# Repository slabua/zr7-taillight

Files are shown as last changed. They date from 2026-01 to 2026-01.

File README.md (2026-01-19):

# ZR-7 ATtiny85 Tail Light







###### tags: `SLBLabs` `SLB Labs` `ZR-7` `ZR7` `ZR750` `Kawasaki` `KawasakiZR7` `TailLight` `TailLights` `ATtiny` `ATtiny85` `Arduino` `C/C++`

## A custom motorcycle tail light based on ATtiny85
> Hardware • Firmware • Animations • Automotive-grade considerations

Front

---

## ✦ Overview

The **ZR-7 Tail Light** is a custom-designed motorcycle tail light built around the **ATtiny85** microcontroller.  
It spans the complete stack, from schematic and PCB design to low-level firmware and animation logic, with a focus on robustness, simplicity, and visual clarity.

The goal of this project is not only to function as a tail light, but to serve as a well-engineered embedded system suitable for real automotive environments.

---

## ✦ Features

- ATtiny85-based control logic
- Addressable RGB LED layout
- Distinct operating modes:
  - Tail / running light
  - Brake light
  - Left / right indicators
- Deterministic, non-blocking firmware
- Designed for 12 V motorcycle electrical systems
- Compact, purpose-built PCB

---

## ✦ Hardware

Front-PCB3D

Front-PCB

### Core Components

- **MCU:** ATtiny85
- **LEDs:** Addressable RGB LEDs
- **Power:** 12 V input with on-board regulation
- **Inputs:** Brake, left indicator, right indicator

### Design Notes

Several constraints influenced the hardware design:

- **Automotive signal noise**
  Input conditioning and pull-down strategies are used to avoid floating or unstable states.

- **Power integrity**
  The circuit is designed to tolerate voltage fluctuations typical of motorcycle electrical systems.

- **Mechanical constraints**
  PCB shape, connector placement, and LED layout are optimized for the tail light enclosure.

Schematics, PCB layouts, and manufacturing files are included in the `hardware/` directory.

---

## ✦ Firmware

Firmware is written in **C**, targeting the ATtiny85 directly, with no operating system or dynamic memory usage.

### Architecture Highlights

- **State-based rendering**
  Tail, brake, and indicator logic are resolved into a single rendering pipeline.

- **Time-driven animations**
  All animations are non-blocking and tick-based.

- **Config-ready architecture**
  The firmware structure allows future addition of persistent configuration if needed.

Firmware source is located in the `firmware/` directory.

---

## ✦ Build & Flashing

The firmware is developed and flashed using the **Arduino IDE** with an external ISP programmer.

### Requirements

- Arduino IDE
- ATtiny board core (e.g. **ATTinyCore** by Spence Konde)
- Adafruit_NeoPixel library
- ISP programmer:
  - USBtinyISP
  - USBasp

### Arduino IDE Setup

1. Install the ATtiny board package via the Boards Manager.
2. Install the Adafruit_NeoPixel library via the Library Manager.
2. Connect the ISP programmer to the ATtiny85 ISP header.
3. In the Arduino IDE, configure:
   - **Board:** ATtiny85
   - **Clock:** 16.5 MHz
   - **B.O.D Level:** 4.3v
   - **Programmer:** USBtinyISP or USBasp

### Flashing

Use:

``Sketch → Upload Using Programmer``

This compiles the firmware and flashes it directly to the ATtiny85.  
No bootloader is used.

---

## ✦ Media

### PCB details


<details>
  <summary>[More]</summary>
  
  
  
  
  
</details>

---

### PCB assembly


<details>
  <summary>[More]</summary>
  
  
  
  
  
  
</details>

---

### Diffuser

  
<details>
  <summary>[More]</summary>

  
  
  
  
  
</details>

---

### Relay

  
<details>
  <summary>[More]</summary>

  
  
  
  
</details>

---

- [TODO] Installed tail light images
- [TODO] Short animation demo videos

※ Attached photographs of the assembled PCB are representative of Rev 1.0.

---

## ✦ Repository Layout

```
zr7-taillight/
├── firmware/        # ATtiny85 firmware source
├── hardware/        # Schematics and PCB design
├── docs/            # Images and additional documentation
└── README.md
```

---

## ✦ Safety & Disclaimer

⚠️ **Important Notice**

This project is provided **as-is**, for educational and experimental purposes.

- The author makes **no guarantees** regarding road legality, safety compliance, or fitness for any particular vehicle.
- Modifying vehicle lighting may be regulated or restricted depending on jurisdiction.
- You are solely responsible for ensuring that any implementation complies with **local laws**, **vehicle regulations**, and **safety requirements**.

Use at your own risk.

---

## ✦ Sponsorship

This project is sponsored by **PCBWay**.

PCBWay provided support for PCB manufacturing during the prototyping and validation stages of this project.

It was my first time trying their services and I am pleased with the results.  
The order flow was a little different than what I was used to, but I have been diligently followed thorough the whole process.  
Other than PCB manufacturing, PCBWay also offers services such as CNC and 3D printing. Be sure to check them out at https://www.pcbway.com/

---

## ✦ License

Released under the **MIT License**.
See the `LICENSE` file for details.

---

## ✦ Project Status

The project is **functional and actively evolving**.
Both hardware and firmware are stable, with ongoing refinements and documentation improvements planned.

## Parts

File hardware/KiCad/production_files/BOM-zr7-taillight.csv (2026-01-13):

Comment | Designator | Footprint | LCSC | Quantity
SMAJ5.0A | D3,D4,D5 | D_SMA | C113952 | 3
100n | C2,C3,C4,C5 | C_0603_1608Metric | C14663 | 4
SMBJ14A | D2 | D_SMB | C152106 | 1
10k | R1 | R_0805_2012Metric | C17414 | 1
1k | R4,R5,R6 | R_0805_2012Metric | C17513 | 3
22k | R10,R11,R12 | R_0805_2012Metric | C17560 | 3
330 | R16,R2,R3 | R_0805_2012Metric | C17630 | 3
4k7 | R7,R8,R9 | R_0805_2012Metric | C17673 | 3
1u | C6,C7,C8 | C_1206_3216Metric | C1848 | 3
D_Schottky | D1 | D_SMA | C22452 | 1
39k | R13,R14,R15 | R_0805_2012Metric | C25826 | 3
Polyfuse | F1 | SLB-Fuse_1812_4532Metric | C2843993 | 1
SW_DPDT_x2 | SW1 | SW_CK_JS202011CQN_DPDT_Straight | C431542 | 1
100u | C1 | CP_Elec_6.3x5.7 | C493460 | 1
Conn_01x04_Pin | J1 | SLB-Mini_DCDC | C5116483 | 1
WS2815 | U1,U10,U100,U11,U12,U13,U14,U15,U16,U17,U18,U19,U2,U20,U21,U22,U23,U24,U25,U26,U27,U28,U29,U3,U30,U31,U32,U33,U34,U35,U36,U37,U38,U39,U4,U40,U41,U42,U43,U44,U45,U46,U47,U48,U49,U5,U50,U51,U52,U53,U54,U55,U56,U57,U58,U59,U6,U60,U61,U62,U63,U64,U65,U66,U67,U68,U69,U7,U70,U71,U72,U73,U74,U75,U76,U77,U78,U79,U8,U80,U81,U82,U83,U84,U85,U86,U87,U88,U89,U9,U90,U91,U92,U93,U94,U95,U96,U97,U98,U99 | LED-TRICOLOR-5050 | C5446699 | 100
Conn_02x04_Counter_Clockwise | J2 | DIP-8_W7.62mm_Socket | C72129 | 1

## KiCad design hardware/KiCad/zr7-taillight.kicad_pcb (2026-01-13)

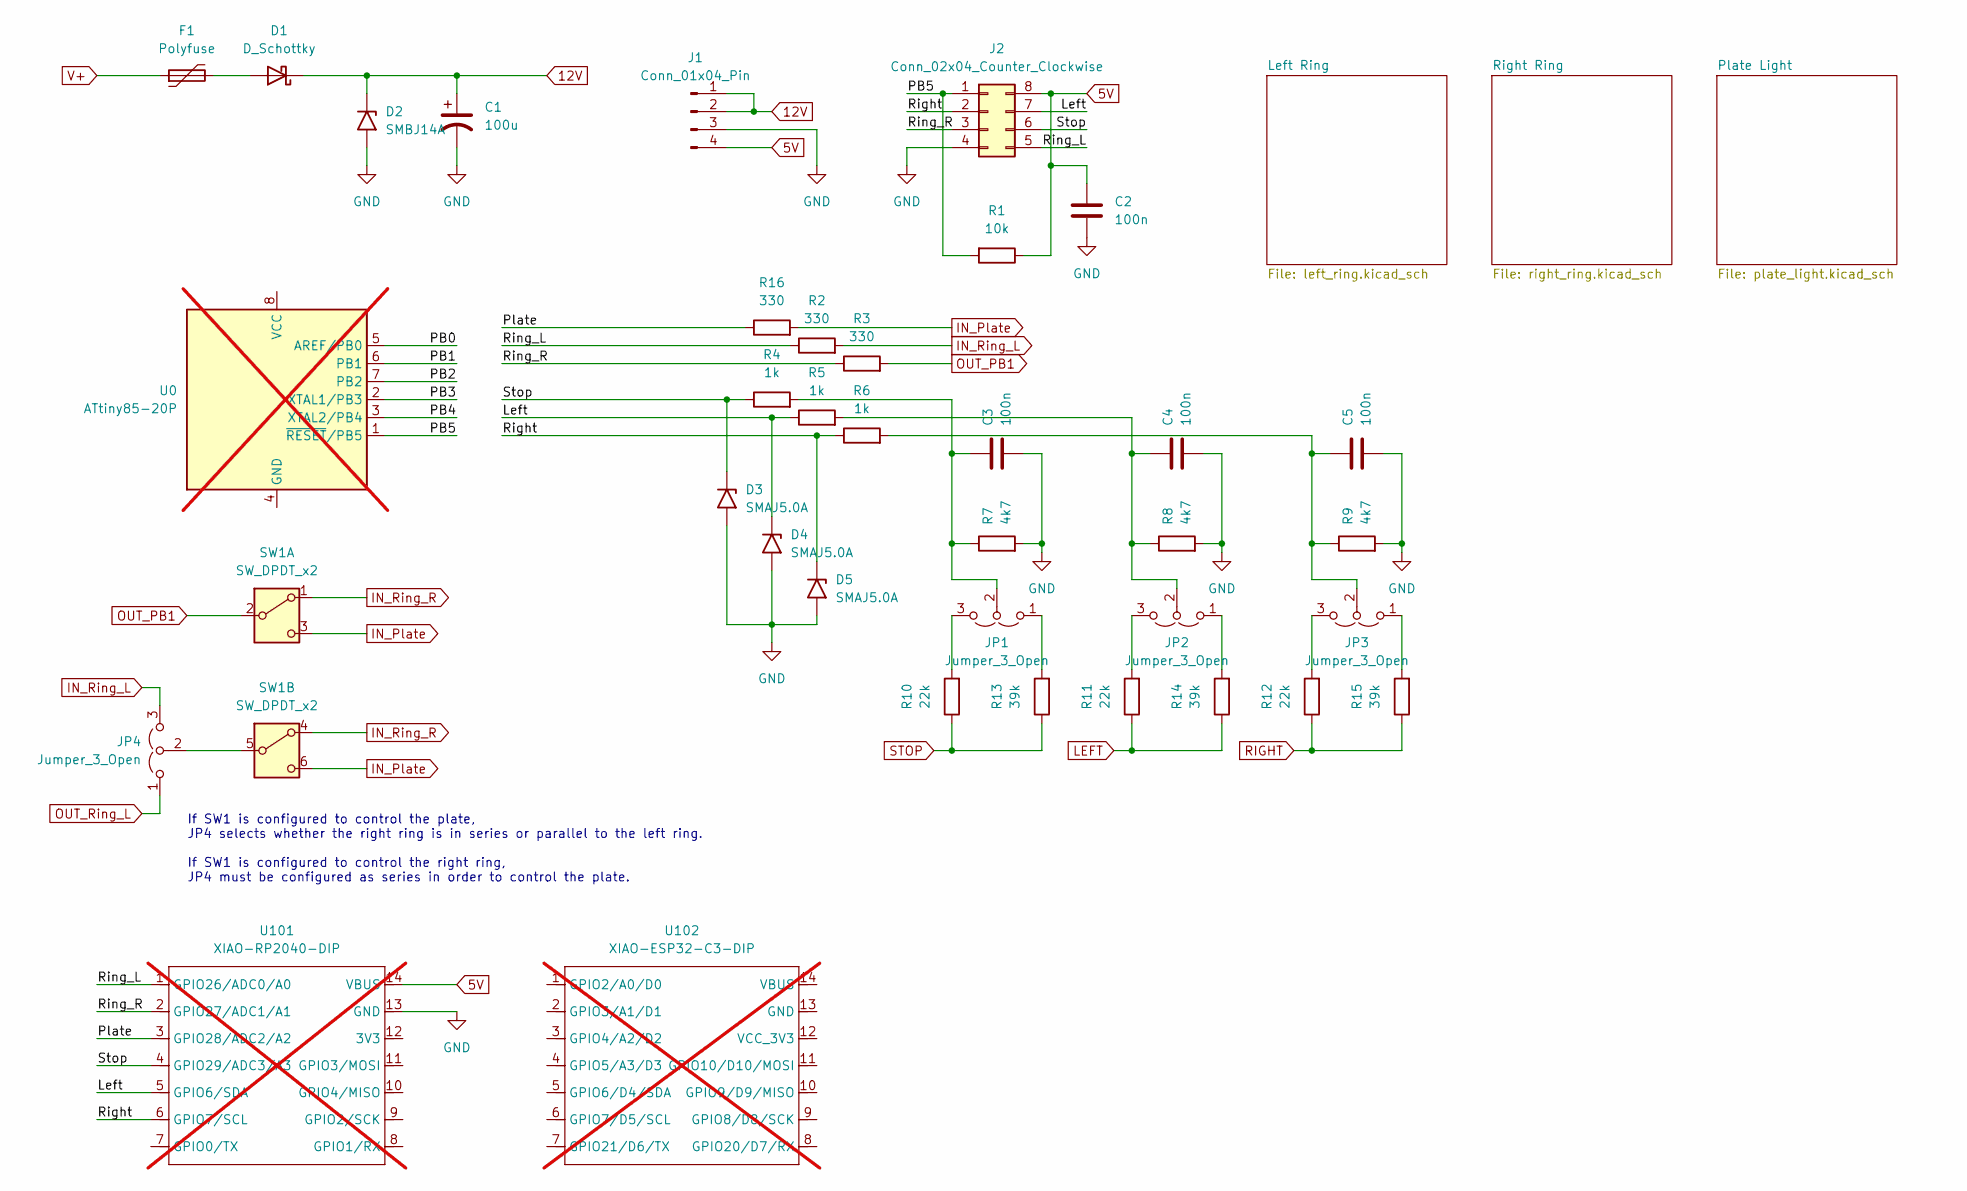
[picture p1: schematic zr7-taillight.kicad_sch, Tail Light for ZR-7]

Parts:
C1: 100u; CP_Elec_6.3x5.7; LCSC C493460
C2, C3, C4, C5: 100n; C_0603_1608Metric; LCSC C14663
D1: D_Schottky; D_SMA; LCSC C22452
D2: SMBJ14A; D_SMB; LCSC C152106
D3, D4, D5: SMAJ5.0A; D_SMA; LCSC C113952
F1: Polyfuse; SLB-Fuse_1812_4532Metric; LCSC C2843993
J1: Conn_01x04_Pin; SLB-Mini_DCDC; LCSC C5116483
J2: Conn_02x04_Counter_Clockwise; DIP-8_W7.62mm_Socket; LCSC C72129
JP1, JP2, JP3, JP4: Jumper_3_Open; PinHeader_1x03_P2.54mm_Vertical; LCSC C49257
R1: 10k; R_0805_2012Metric; LCSC C17414
R2, R3, R16: 330; R_0805_2012Metric; LCSC C17630
R4, R5, R6: 1k; R_0805_2012Metric; LCSC C17513
R7, R8, R9: 4k7; R_0805_2012Metric; LCSC C17673
R10, R11, R12: 22k; R_0805_2012Metric; LCSC C17560
R13, R14, R15: 39k; R_0805_2012Metric; LCSC C25826
SW1: SW_DPDT_x2; SW_CK_JS202011CQN_DPDT_Straight; LCSC C431542
U0: ATtiny85-20P; DIP-8_W7.62mm; not fitted
U101: XIAO-RP2040-DIP; not fitted
U102: XIAO-ESP32-C3-DIP; MOUDLE14P-XIAO-DIP-SMD; not fitted

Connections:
5V: C2.1, J1.4, J2.8, R1.1, U101.14 (VBUS)
12V: C1.1, D1.1 (K), D2.1 (A1), J1.1, J1.2; also elsewhere on the board
/Left: D4.1 (A1), J2.7, R5.1, U101.5 (GPIO6/SDA)
/PB5: J2.1, R1.2, U0.1 (~RESET/PB5)
/Plate: R16.1, U101.3 (GPIO28/ADC2/A2)
/Right: D5.1 (A1), J2.2, R6.1, U101.6 (GPIO7/SCL)
/Ring_L: J2.5, R2.1, U101.1 (GPIO26/ADC0/A0)
/Ring_R: J2.3, R3.1, U101.2 (GPIO27/ADC1/A1)
/Stop: D3.1 (A1), J2.6, R4.1, U101.4 (GPIO29/ADC3/A3)
GND: C1.2, C2.2, C3.2, C4.2, C5.2, D2.2 (A2), D3.2 (A2), D4.2 (A2), D5.2 (A2), J1.3, J2.4, R7.2, R8.2, R9.2, U101.13 (GND); also elsewhere on the board
IN_Plate: R16.2, SW1.3 (C), SW1.6 (C); also elsewhere on the board
IN_Ring_L: JP4.3 (B), R2.2; also elsewhere on the board
IN_Ring_R: SW1.1 (A), SW1.4 (A); also elsewhere on the board
LEFT: R11.1, R14.1
unnamed: D1.2 (A), F1.2
unnamed: JP1.1 (A), R13.2
unnamed: JP1.3 (B), R10.2
unnamed: C3.1, JP1.2 (C), R4.2, R7.1
unnamed: JP2.1 (A), R14.2
unnamed: JP2.3 (B), R11.2
unnamed: C4.1, JP2.2 (C), R5.2, R8.1
unnamed: JP3.1 (A), R15.2
unnamed: JP3.3 (B), R12.2
unnamed: C5.1, JP3.2 (C), R6.2, R9.1
unnamed: JP4.2 (C), SW1.5 (B)
OUT_PB1: R3.2, SW1.2 (B)
OUT_Ring_L: JP4.1 (A); also elsewhere on the board
RIGHT: R12.1, R15.1
STOP: R10.1, R13.1
V+: F1.1

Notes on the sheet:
If SW1 is configured to control the plate, JP4 selects whether the right ring is in series or parallel to the left ring. If SW1 is configured to control the right ring, JP4 must be configured as series in order to control the plate.

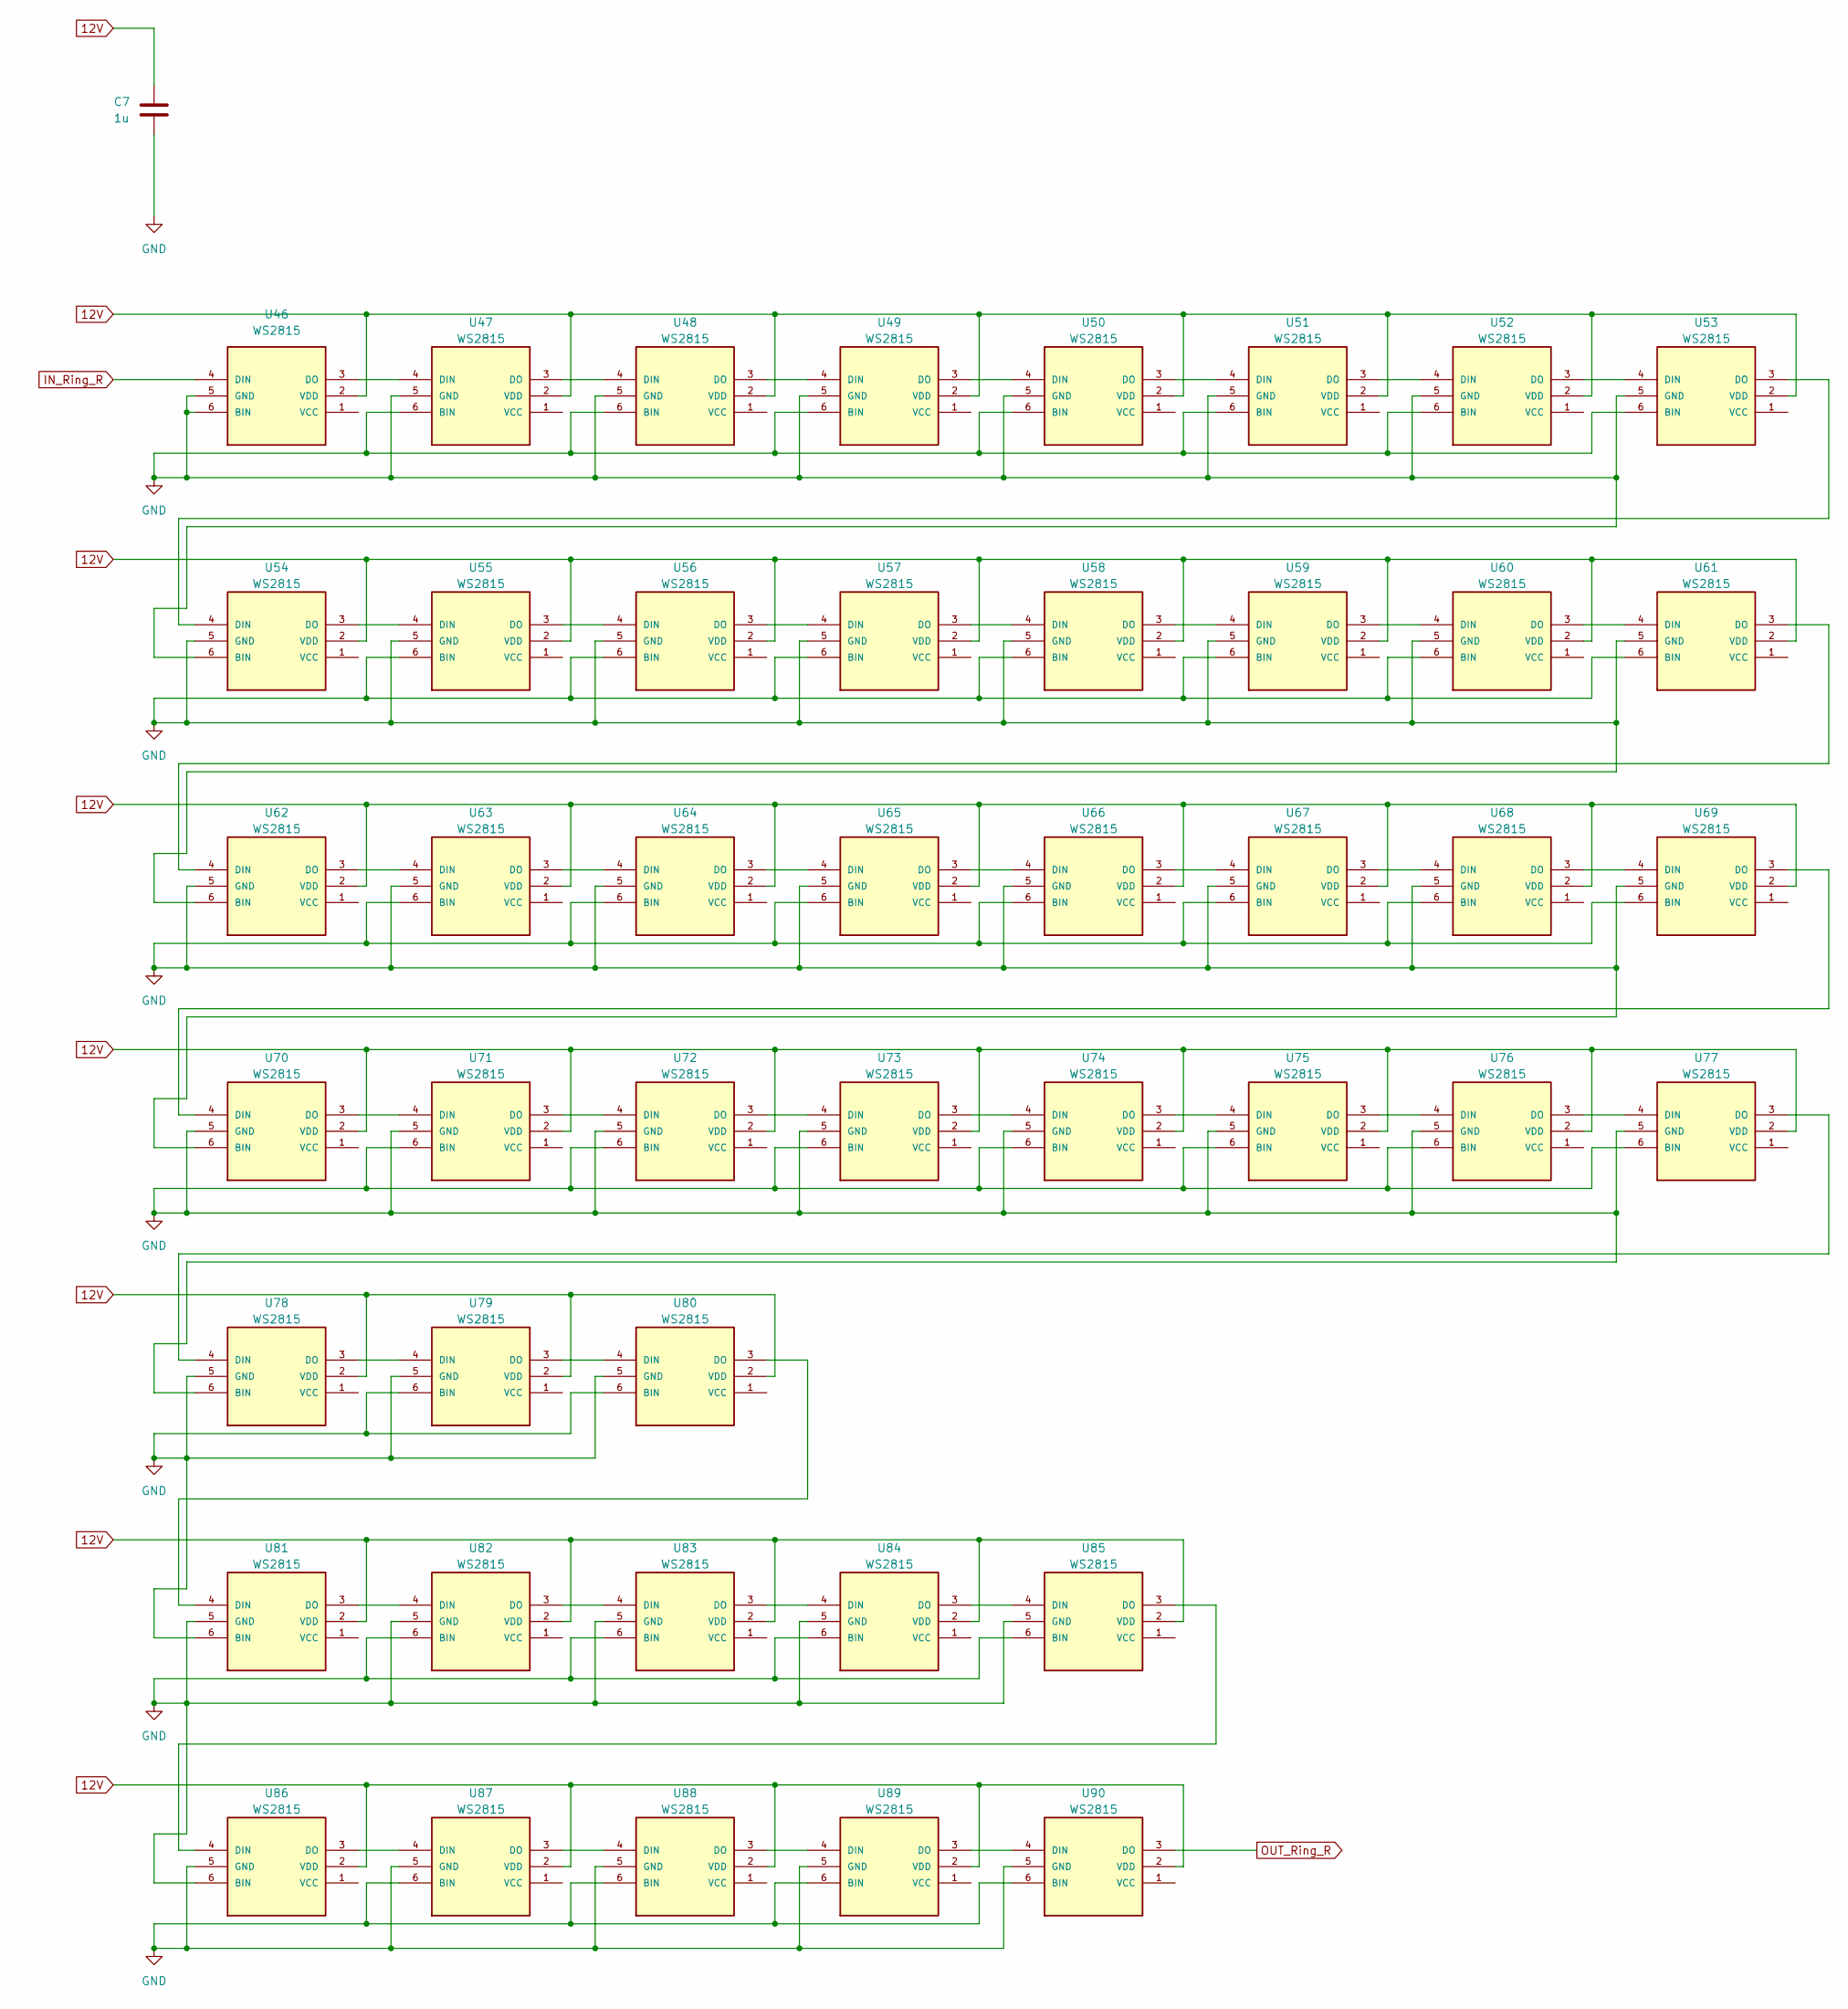
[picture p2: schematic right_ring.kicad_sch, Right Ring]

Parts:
C7: 1u; C_1206_3216Metric; LCSC C1848
U46, U47, U48, U49, U50, U51, U52, U53, U54, U55, U56, U57, U58, U59, U60, U61, U62, U63, U64, U65, U66, U67, U68, U69, U70, U71, U72, U73, U74, U75, U76, U77, U78, U79, U80, U81, U82, U83, U84, U85, U86, U87, U88, U89, U90: WS2815; LED-TRICOLOR-5050; LCSC C5446699

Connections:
12V: C7.1, U46.2 (VDD), U47.2 (VDD), U48.2 (VDD), U49.2 (VDD), U50.2 (VDD), U51.2 (VDD), U52.2 (VDD), U53.2 (VDD), U54.2 (VDD), U55.2 (VDD), U56.2 (VDD), U57.2 (VDD), U58.2 (VDD), U59.2 (VDD), U60.2 (VDD), U61.2 (VDD), U62.2 (VDD), U63.2 (VDD), U64.2 (VDD), U65.2 (VDD), U66.2 (VDD), U67.2 (VDD), U68.2 (VDD), U69.2 (VDD), U70.2 (VDD), U71.2 (VDD), U72.2 (VDD), U73.2 (VDD), U74.2 (VDD), U75.2 (VDD), U76.2 (VDD), U77.2 (VDD), U78.2 (VDD), U79.2 (VDD), U80.2 (VDD), U81.2 (VDD), U82.2 (VDD), U83.2 (VDD), U84.2 (VDD), U85.2 (VDD), U86.2 (VDD), U87.2 (VDD), U88.2 (VDD), U89.2 (VDD), U90.2 (VDD); also elsewhere on the board
GND: C7.2, U46.5 (GND), U46.6 (BIN), U47.5 (GND), U47.6 (BIN), U48.5 (GND), U48.6 (BIN), U49.5 (GND), U49.6 (BIN), U50.5 (GND), U50.6 (BIN), U51.5 (GND), U51.6 (BIN), U52.5 (GND), U52.6 (BIN), U53.5 (GND), U53.6 (BIN), U54.5 (GND), U54.6 (BIN), U55.5 (GND), U55.6 (BIN), U56.5 (GND), U56.6 (BIN), U57.5 (GND), U57.6 (BIN), U58.5 (GND), U58.6 (BIN), U59.5 (GND), U59.6 (BIN), U60.5 (GND), U60.6 (BIN), U61.5 (GND), U61.6 (BIN), U62.5 (GND), U62.6 (BIN), U63.5 (GND), U63.6 (BIN), U64.5 (GND), U64.6 (BIN), U65.5 (GND), U65.6 (BIN), U66.5 (GND), U66.6 (BIN), U67.5 (GND), U67.6 (BIN), U68.5 (GND), U68.6 (BIN), U69.5 (GND), U69.6 (BIN), U70.5 (GND), U70.6 (BIN), U71.5 (GND), U71.6 (BIN), U72.5 (GND), U72.6 (BIN), U73.5 (GND), U73.6 (BIN), U74.5 (GND), U74.6 (BIN), U75.5 (GND), U75.6 (BIN), U76.5 (GND), U76.6 (BIN), U77.5 (GND), U77.6 (BIN), U78.5 (GND), U78.6 (BIN), U79.5 (GND), U79.6 (BIN), U80.5 (GND), U80.6 (BIN), U81.5 (GND), U81.6 (BIN), U82.5 (GND), U82.6 (BIN), U83.5 (GND), U83.6 (BIN), U84.5 (GND), U84.6 (BIN), U85.5 (GND), U85.6 (BIN), U86.5 (GND), U86.6 (BIN), U87.5 (GND), U87.6 (BIN), U88.5 (GND), U88.6 (BIN), U89.5 (GND), U89.6 (BIN), U90.5 (GND), U90.6 (BIN); also elsewhere on the board
IN_Ring_R: U46.4 (DIN); also elsewhere on the board
unnamed: U46.3 (DO), U47.4 (DIN)
unnamed: U47.3 (DO), U48.4 (DIN)
unnamed: U48.3 (DO), U49.4 (DIN)
unnamed: U49.3 (DO), U50.4 (DIN)
unnamed: U50.3 (DO), U51.4 (DIN)
unnamed: U51.3 (DO), U52.4 (DIN)
unnamed: U52.3 (DO), U53.4 (DIN)
unnamed: U53.3 (DO), U54.4 (DIN)
unnamed: U54.3 (DO), U55.4 (DIN)
unnamed: U55.3 (DO), U56.4 (DIN)
unnamed: U56.3 (DO), U57.4 (DIN)
unnamed: U57.3 (DO), U58.4 (DIN)
unnamed: U58.3 (DO), U59.4 (DIN)
unnamed: U59.3 (DO), U60.4 (DIN)
unnamed: U60.3 (DO), U61.4 (DIN)
unnamed: U61.3 (DO), U62.4 (DIN)
unnamed: U62.3 (DO), U63.4 (DIN)
unnamed: U63.3 (DO), U64.4 (DIN)
unnamed: U64.3 (DO), U65.4 (DIN)
unnamed: U65.3 (DO), U66.4 (DIN)
unnamed: U66.3 (DO), U67.4 (DIN)
unnamed: U67.3 (DO), U68.4 (DIN)
unnamed: U68.3 (DO), U69.4 (DIN)
unnamed: U69.3 (DO), U70.4 (DIN)
unnamed: U70.3 (DO), U71.4 (DIN)
unnamed: U71.3 (DO), U72.4 (DIN)
unnamed: U72.3 (DO), U73.4 (DIN)
unnamed: U73.3 (DO), U74.4 (DIN)
unnamed: U74.3 (DO), U75.4 (DIN)
unnamed: U75.3 (DO), U76.4 (DIN)
unnamed: U76.3 (DO), U77.4 (DIN)
unnamed: U77.3 (DO), U78.4 (DIN)
unnamed: U78.3 (DO), U79.4 (DIN)
unnamed: U79.3 (DO), U80.4 (DIN)
unnamed: U80.3 (DO), U81.4 (DIN)
unnamed: U81.3 (DO), U82.4 (DIN)
unnamed: U82.3 (DO), U83.4 (DIN)
unnamed: U83.3 (DO), U84.4 (DIN)
unnamed: U84.3 (DO), U85.4 (DIN)
unnamed: U85.3 (DO), U86.4 (DIN)
unnamed: U86.3 (DO), U87.4 (DIN)
unnamed: U87.3 (DO), U88.4 (DIN)
unnamed: U88.3 (DO), U89.4 (DIN)
unnamed: U89.3 (DO), U90.4 (DIN)
OUT_Ring_R: U90.3 (DO)

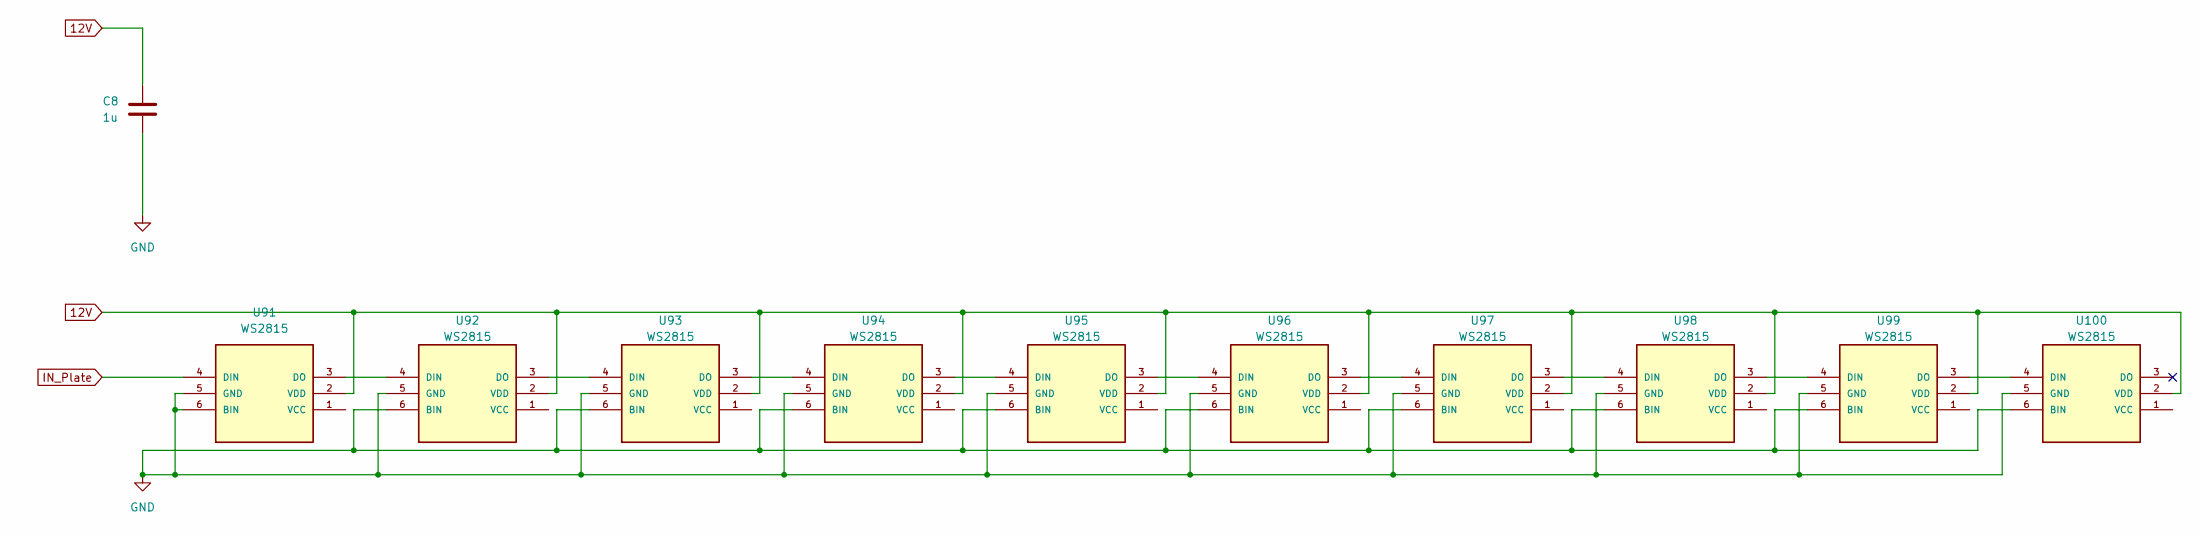
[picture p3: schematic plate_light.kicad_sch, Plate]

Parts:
C8: 1u; C_1206_3216Metric; LCSC C1848
U91, U92, U93, U94, U95, U96, U97, U98, U99, U100: WS2815; LED-TRICOLOR-5050; LCSC C5446699

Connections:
12V: C8.1, U91.2 (VDD), U92.2 (VDD), U93.2 (VDD), U94.2 (VDD), U95.2 (VDD), U96.2 (VDD), U97.2 (VDD), U98.2 (VDD), U99.2 (VDD), U100.2 (VDD); also elsewhere on the board
GND: C8.2, U91.5 (GND), U91.6 (BIN), U92.5 (GND), U92.6 (BIN), U93.5 (GND), U93.6 (BIN), U94.5 (GND), U94.6 (BIN), U95.5 (GND), U95.6 (BIN), U96.5 (GND), U96.6 (BIN), U97.5 (GND), U97.6 (BIN), U98.5 (GND), U98.6 (BIN), U99.5 (GND), U99.6 (BIN), U100.5 (GND), U100.6 (BIN); also elsewhere on the board
IN_Plate: U91.4 (DIN); also elsewhere on the board
unnamed: U91.3 (DO), U92.4 (DIN)
unnamed: U92.3 (DO), U93.4 (DIN)
unnamed: U93.3 (DO), U94.4 (DIN)
unnamed: U94.3 (DO), U95.4 (DIN)
unnamed: U95.3 (DO), U96.4 (DIN)
unnamed: U96.3 (DO), U97.4 (DIN)
unnamed: U97.3 (DO), U98.4 (DIN)
unnamed: U98.3 (DO), U99.4 (DIN)
unnamed: U99.3 (DO), U100.4 (DIN)

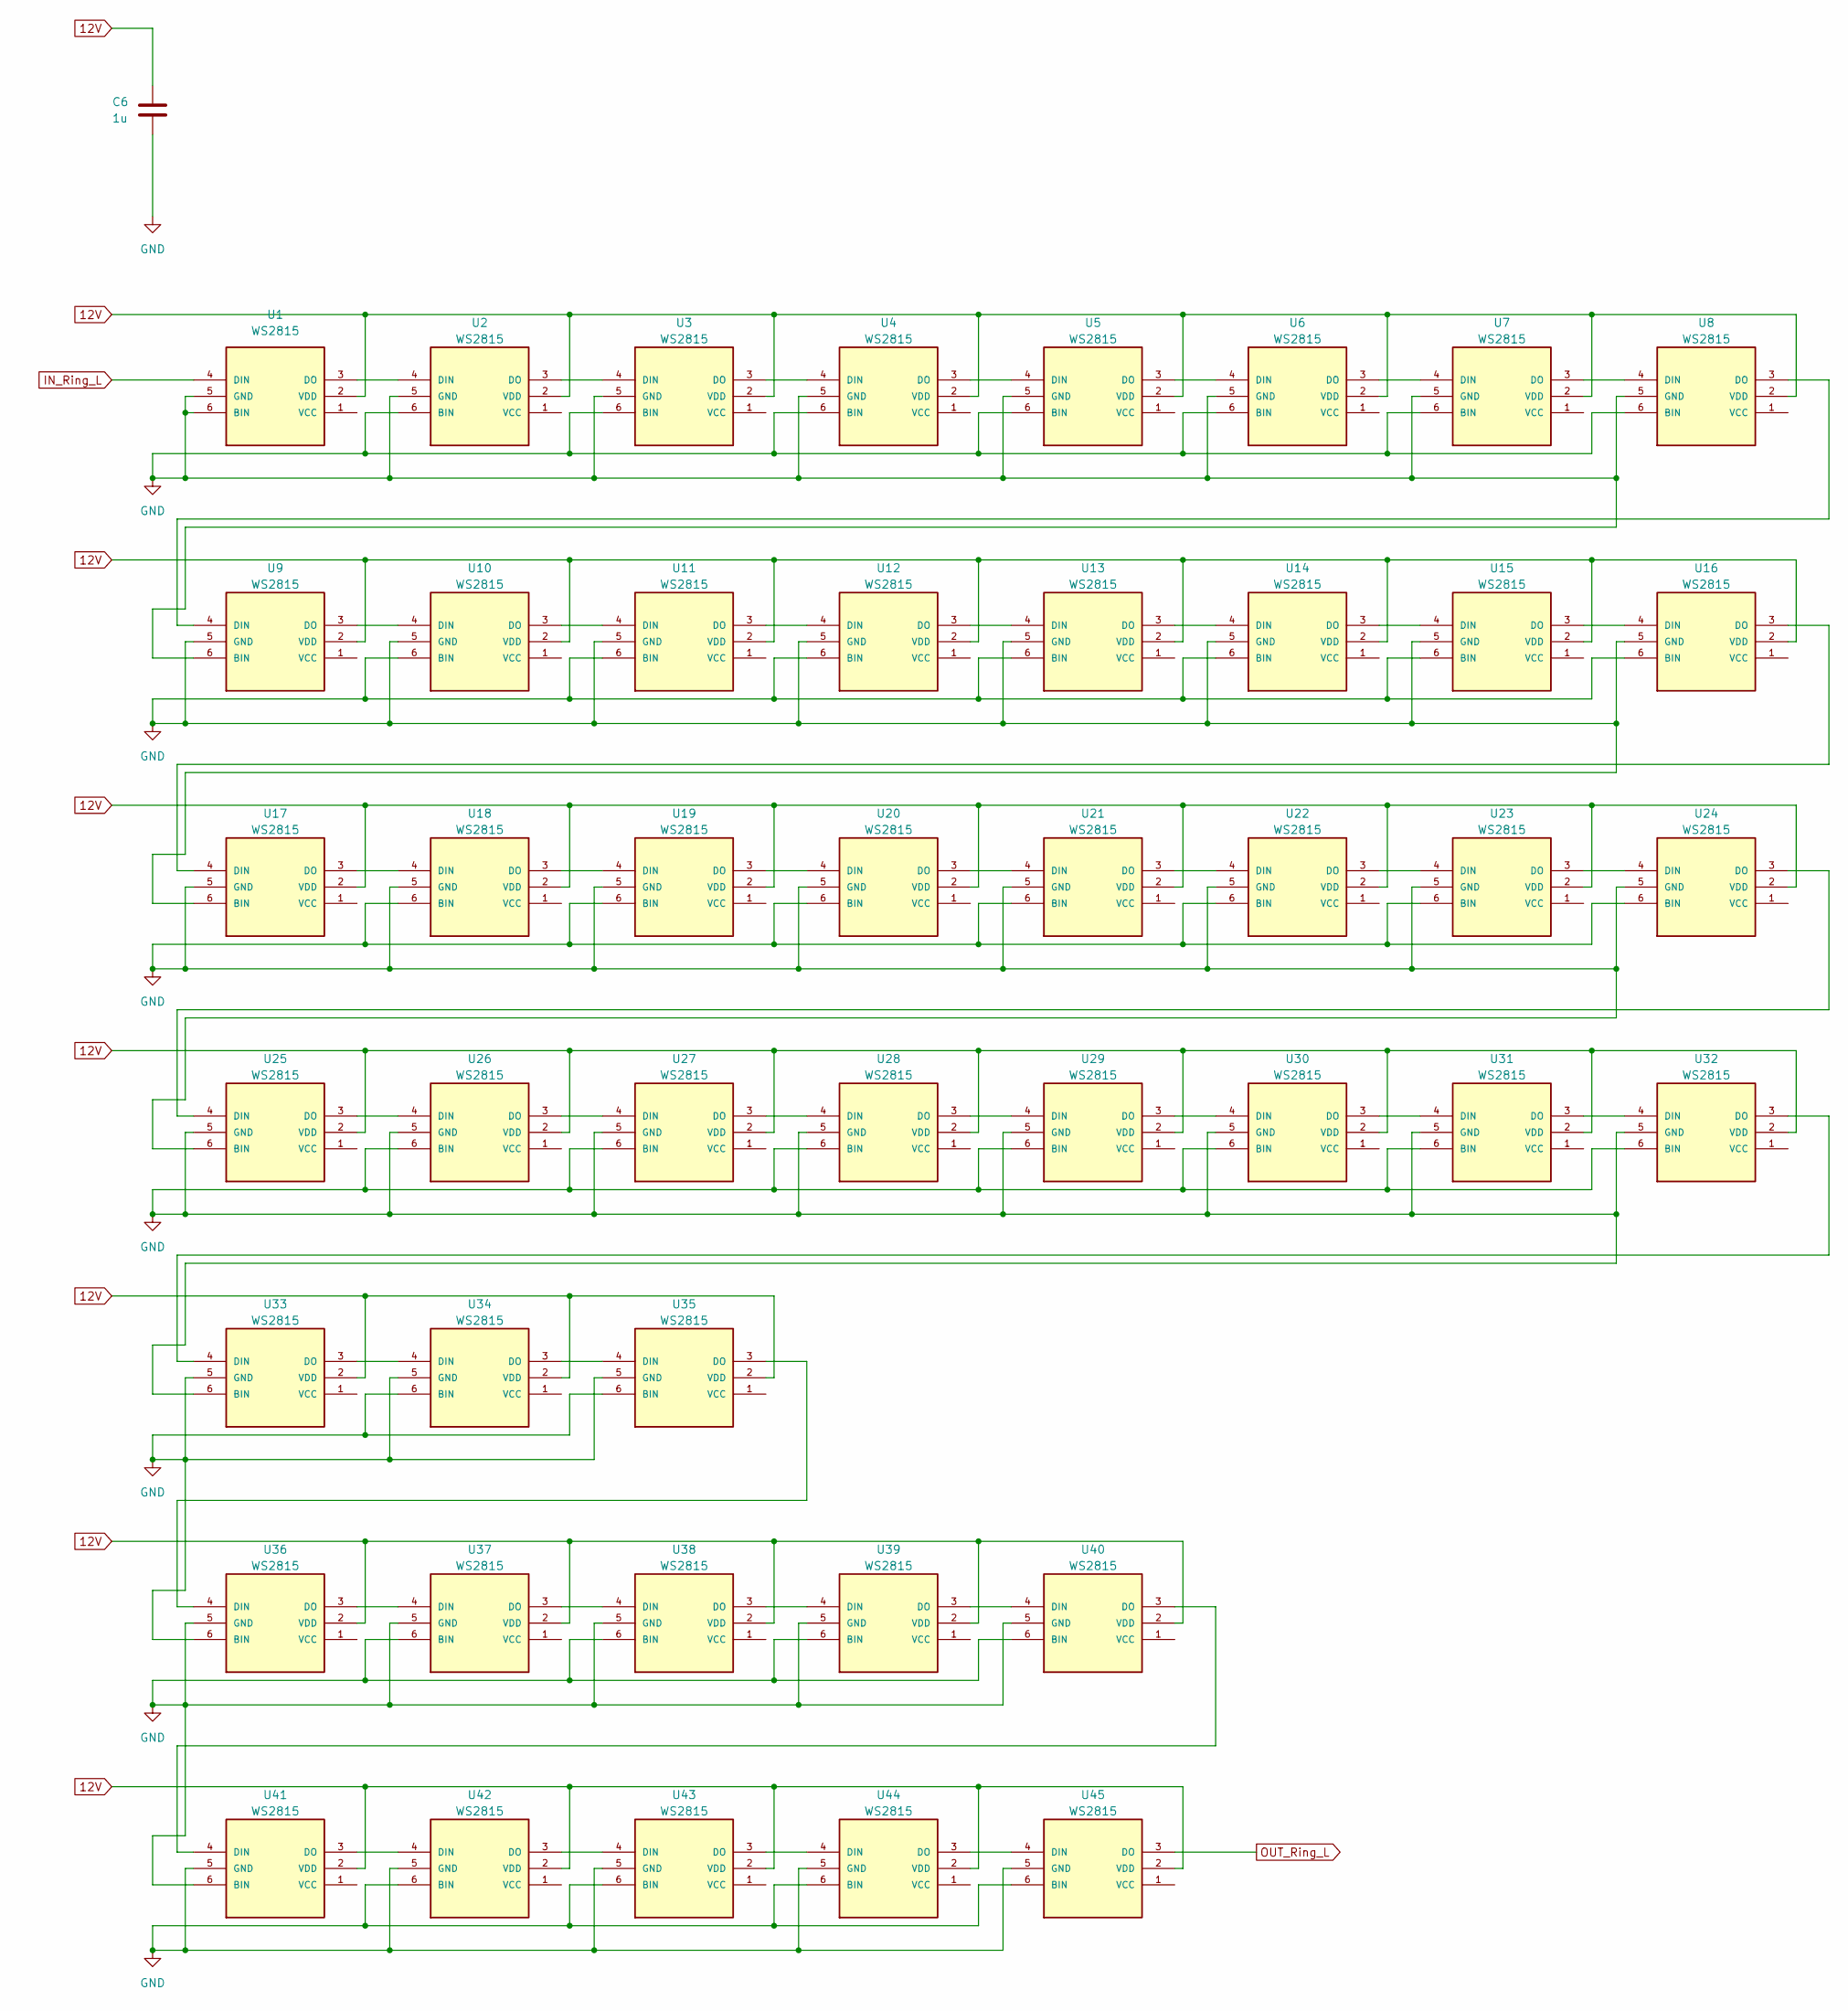
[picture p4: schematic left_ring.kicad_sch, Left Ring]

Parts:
C6: 1u; C_1206_3216Metric; LCSC C1848
U1, U2, U3, U4, U5, U6, U7, U8, U9, U10, U11, U12, U13, U14, U15, U16, U17, U18, U19, U20, U21, U22, U23, U24, U25, U26, U27, U28, U29, U30, U31, U32, U33, U34, U35, U36, U37, U38, U39, U40, U41, U42, U43, U44, U45: WS2815; LED-TRICOLOR-5050; LCSC C5446699

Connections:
12V: C6.1, U1.2 (VDD), U2.2 (VDD), U3.2 (VDD), U4.2 (VDD), U5.2 (VDD), U6.2 (VDD), U7.2 (VDD), U8.2 (VDD), U9.2 (VDD), U10.2 (VDD), U11.2 (VDD), U12.2 (VDD), U13.2 (VDD), U14.2 (VDD), U15.2 (VDD), U16.2 (VDD), U17.2 (VDD), U18.2 (VDD), U19.2 (VDD), U20.2 (VDD), U21.2 (VDD), U22.2 (VDD), U23.2 (VDD), U24.2 (VDD), U25.2 (VDD), U26.2 (VDD), U27.2 (VDD), U28.2 (VDD), U29.2 (VDD), U30.2 (VDD), U31.2 (VDD), U32.2 (VDD), U33.2 (VDD), U34.2 (VDD), U35.2 (VDD), U36.2 (VDD), U37.2 (VDD), U38.2 (VDD), U39.2 (VDD), U40.2 (VDD), U41.2 (VDD), U42.2 (VDD), U43.2 (VDD), U44.2 (VDD), U45.2 (VDD); also elsewhere on the board
GND: C6.2, U1.5 (GND), U1.6 (BIN), U2.5 (GND), U2.6 (BIN), U3.5 (GND), U3.6 (BIN), U4.5 (GND), U4.6 (BIN), U5.5 (GND), U5.6 (BIN), U6.5 (GND), U6.6 (BIN), U7.5 (GND), U7.6 (BIN), U8.5 (GND), U8.6 (BIN), U9.5 (GND), U9.6 (BIN), U10.5 (GND), U10.6 (BIN), U11.5 (GND), U11.6 (BIN), U12.5 (GND), U12.6 (BIN), U13.5 (GND), U13.6 (BIN), U14.5 (GND), U14.6 (BIN), U15.5 (GND), U15.6 (BIN), U16.5 (GND), U16.6 (BIN), U17.5 (GND), U17.6 (BIN), U18.5 (GND), U18.6 (BIN), U19.5 (GND), U19.6 (BIN), U20.5 (GND), U20.6 (BIN), U21.5 (GND), U21.6 (BIN), U22.5 (GND), U22.6 (BIN), U23.5 (GND), U23.6 (BIN), U24.5 (GND), U24.6 (BIN), U25.5 (GND), U25.6 (BIN), U26.5 (GND), U26.6 (BIN), U27.5 (GND), U27.6 (BIN), U28.5 (GND), U28.6 (BIN), U29.5 (GND), U29.6 (BIN), U30.5 (GND), U30.6 (BIN), U31.5 (GND), U31.6 (BIN), U32.5 (GND), U32.6 (BIN), U33.5 (GND), U33.6 (BIN), U34.5 (GND), U34.6 (BIN), U35.5 (GND), U35.6 (BIN), U36.5 (GND), U36.6 (BIN), U37.5 (GND), U37.6 (BIN), U38.5 (GND), U38.6 (BIN), U39.5 (GND), U39.6 (BIN), U40.5 (GND), U40.6 (BIN), U41.5 (GND), U41.6 (BIN), U42.5 (GND), U42.6 (BIN), U43.5 (GND), U43.6 (BIN), U44.5 (GND), U44.6 (BIN), U45.5 (GND), U45.6 (BIN); also elsewhere on the board
IN_Ring_L: U1.4 (DIN); also elsewhere on the board
unnamed: U1.3 (DO), U2.4 (DIN)
unnamed: U2.3 (DO), U3.4 (DIN)
unnamed: U3.3 (DO), U4.4 (DIN)
unnamed: U4.3 (DO), U5.4 (DIN)
unnamed: U5.3 (DO), U6.4 (DIN)
unnamed: U6.3 (DO), U7.4 (DIN)
unnamed: U7.3 (DO), U8.4 (DIN)
unnamed: U8.3 (DO), U9.4 (DIN)
unnamed: U9.3 (DO), U10.4 (DIN)
unnamed: U10.3 (DO), U11.4 (DIN)
unnamed: U11.3 (DO), U12.4 (DIN)
unnamed: U12.3 (DO), U13.4 (DIN)
unnamed: U13.3 (DO), U14.4 (DIN)
unnamed: U14.3 (DO), U15.4 (DIN)
unnamed: U15.3 (DO), U16.4 (DIN)
unnamed: U16.3 (DO), U17.4 (DIN)
unnamed: U17.3 (DO), U18.4 (DIN)
unnamed: U18.3 (DO), U19.4 (DIN)
unnamed: U19.3 (DO), U20.4 (DIN)
unnamed: U20.3 (DO), U21.4 (DIN)
unnamed: U21.3 (DO), U22.4 (DIN)
unnamed: U22.3 (DO), U23.4 (DIN)
unnamed: U23.3 (DO), U24.4 (DIN)
unnamed: U24.3 (DO), U25.4 (DIN)
unnamed: U25.3 (DO), U26.4 (DIN)
unnamed: U26.3 (DO), U27.4 (DIN)
unnamed: U27.3 (DO), U28.4 (DIN)
unnamed: U28.3 (DO), U29.4 (DIN)
unnamed: U29.3 (DO), U30.4 (DIN)
unnamed: U30.3 (DO), U31.4 (DIN)
unnamed: U31.3 (DO), U32.4 (DIN)
unnamed: U32.3 (DO), U33.4 (DIN)
unnamed: U33.3 (DO), U34.4 (DIN)
unnamed: U34.3 (DO), U35.4 (DIN)
unnamed: U35.3 (DO), U36.4 (DIN)
unnamed: U36.3 (DO), U37.4 (DIN)
unnamed: U37.3 (DO), U38.4 (DIN)
unnamed: U38.3 (DO), U39.4 (DIN)
unnamed: U39.3 (DO), U40.4 (DIN)
unnamed: U40.3 (DO), U41.4 (DIN)
unnamed: U41.3 (DO), U42.4 (DIN)
unnamed: U42.3 (DO), U43.4 (DIN)
unnamed: U43.3 (DO), U44.4 (DIN)
unnamed: U44.3 (DO), U45.4 (DIN)
OUT_Ring_L: U45.3 (DO); also elsewhere on the board

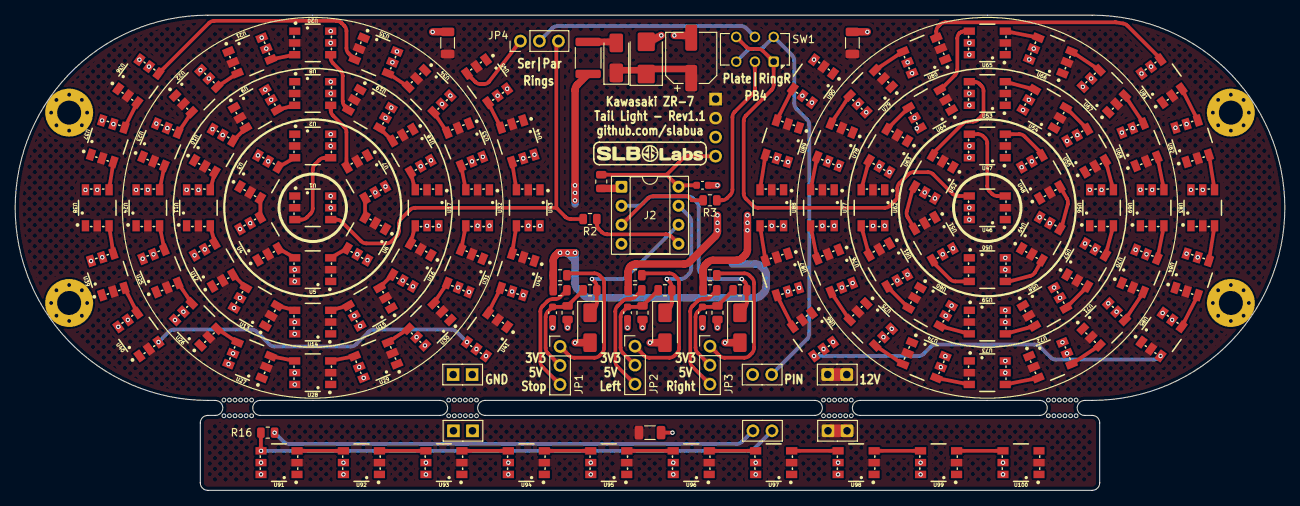
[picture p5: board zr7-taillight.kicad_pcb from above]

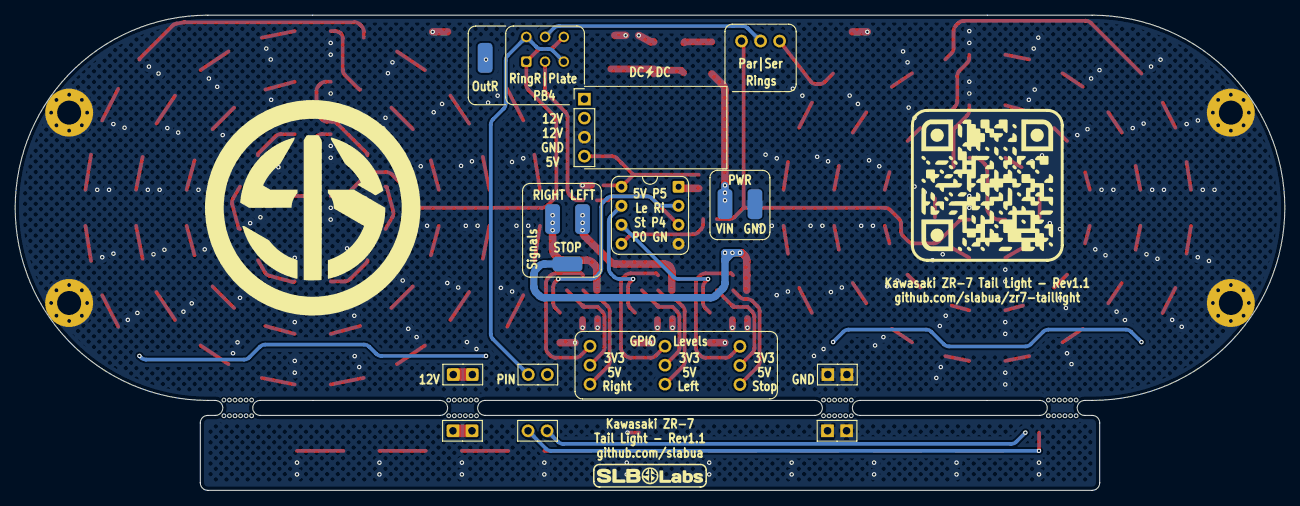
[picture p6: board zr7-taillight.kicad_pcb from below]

Board: 2 copper layers, 169.4 x 63.4 mm, 138 parts (2 on the bottom side), 125 nets.

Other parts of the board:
Ref**: SLBLabs LOGO only w-border

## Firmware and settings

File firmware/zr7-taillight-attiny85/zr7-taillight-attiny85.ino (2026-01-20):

// PB0: rings (Left + Right in parallel, mirrored, 45 LEDs total)
// PB4: numberplate (10 LEDs)
// Wiring Colour Codes
// Idle:  White (PWR)
// Stop:  Red
// Left:  Blue
// Right: Yellow
// GND:   Black (GND)

#include <Adafruit_NeoPixel.h>

// ---------------- CONFIG ----------------
#define RING_LEDS               45
#define PLATE_LEDS              10

#define RINGS_PIN               PB0
#define PLATE_PIN               PB4

#define PIN_STOP                PB1
#define PIN_LEFT                PB2
#define PIN_RIGHT               PB3

#define IDLE_MIN_BRIGHTNESS     5
#define IDLE_MAX_BRIGHTNESS     64
#define IDLE_SPAN               (IDLE_MAX_BRIGHTNESS - IDLE_MIN_BRIGHTNESS)
#define IDLE_PERIOD             2000  // breathing animation
#define IDLE_PERIOD_TICKS       (IDLE_PERIOD / 10)

#define STOP_BRIGHTNESS         200   // for R

#define PLATE_BRIGHTNESS        64    // for R, G, B
#define PLATE_TRAIL_LEN         2
//#define PLATE_STOP_TRAIL_LEN  2

#define BLINKER_TIMEOUT         2000
#define BLINKER_TIMEOUT_TICKS   (BLINKER_TIMEOUT / 10)
#define BLINKER_DEBOUNCE        20
#define BLINKER_DEBOUNCE_TICKS  ((BLINKER_DEBOUNCE + 49) / 50)  // 1

#define EMERG_LATCH_TICKS       50    // ~500 ms (confirmation)
#define EMERG_RELEASE_TICKS     150   // ~1.5 s (release)

#define LOOP_DELAY              10    // ms
#define RINGS_EMERG_DELAY       50    // ms
#define LOOP_DIVIDER            10
#define RINGS_EMERG_DIV         10
#define PLATE_STOP_DIV          10
#define RINGS_SWEEP_DIV         2
#define RINGS_SWEEP_TRAIL_LEN   3

#define BLINK_STEP_TICKS        2     // ticks per eyelid step
#define BLINK_INTERVAL_TICKS    500   // interval between blinks

// ---------------- MODE ----------------
enum Mode {
  MODE_IDLE,
  MODE_STOP,
  MODE_LEFT,
  MODE_RIGHT,
  MODE_EMERGENCY
};
static Mode currentMode = MODE_IDLE;

// -------------- EYEBLINK --------------
enum EyeBlinkState {
  BLINK_IDLE,
  BLINK_ACTIVE
};
static EyeBlinkState blinkState = BLINK_IDLE;

// blink sequence
static const int8_t blinkOrder[] = { +3, +2, +1, 0, -1, -2, -3 };
static const uint8_t BLINK_STEPS = sizeof(blinkOrder) / sizeof(blinkOrder[0]);

static bool blinkOpening = false;   // false = closing, true = opening
static int8_t blinkIndex = 0;
static uint8_t blinkTick = 0;

static const int8_t ledY[RING_LEDS] = {
  // ---- center ----
  /*  0 */  0,

  // ---- ring 1 (6) ----
  /*  1 */ +1,  // N
  /*  2 */ +1,
  /*  3 */ -1,
  /*  4 */ -1,  // S
  /*  5 */ -1,
  /*  6 */ +1,

  // ---- ring 2 (12) ----
  /*  7 */ +2,  /*  8 */ +2,      // N arc
  /*  9 */ +2,  /* 10 */  0,
  /* 11 */ -2,  /* 12 */ -2,
  /* 13 */ -2,  /* 14 */ -2,
  /* 15 */ -2,  /* 16 */  0,      // S arc
  /* 17 */ +2,  /* 18 */ +2,

  // ---- ring 3 (16) ----
  /* 19 */ +3,  /* 20 */ +3,  /* 21 */ +3,  // N arc
  /* 22 */ +2,  /* 23 */  0,
  /* 24 */ -2,  /* 25 */ -3,
  /* 26 */ -3,  /* 27 */ -3,
  /* 28 */ -3,  /* 29 */ -3,  /* 30 */ -2,  // S arc
  /* 31 */  0,  /* 32 */ +2,
  /* 33 */ +3,  /* 34 */ +3,

  // ---- left parenthesis (35–39) ----
  /* 35 */ +33,   // near 21
  /* 36 */ +33,
  /* 37 */  30,
  /* 38 */ -33,
  /* 39 */ -33,   // near 25

  // ---- right parenthesis (40–44) ----
  /* 40 */ -33,   // near 29
  /* 41 */ -33,
  /* 42 */  30,
  /* 43 */ +33,
  /* 44 */ +33    // near 33
};

// -------------- EMERGENCY RING BLINK --------------
enum RingEmergState {
  RING_EMERG_IDLE,
  RING_EMERG_ACTIVE
};
static RingEmergState ringEmergState = RING_EMERG_IDLE;

static const int8_t ringOrder[] = { 0, 1, 2, 3, 4 };
static const uint8_t RING_STEPS = sizeof(ringOrder) / sizeof(ringOrder[0]);

static int8_t ringEmergIndex = 0;
static bool ringOpening = false;
static uint8_t ringTick = 0;

static bool     emergencyLatched = false;
static uint16_t emergencyLatchTick = 0;
static uint16_t emergencyReleaseTick = 0;

static const int8_t ledRing[RING_LEDS] = {
  /*  0 */ 0,

  // ring 1
  /*  1 */ 1, /*  2 */ 1, /*  3 */ 1, /*  4 */ 1, /*  5 */ 1, /*  6 */ 1,

  // ring 2
  /*  7 */ 2, /*  8 */ 2, /*  9 */ 2, /* 10 */ 2,
  /* 11 */ 2, /* 12 */ 2, /* 13 */ 2, /* 14 */ 2,
  /* 15 */ 2, /* 16 */ 2,
  /* 17 */ 2, /* 18 */ 2,

  // ring 3
  /* 19 */ 3, /* 20 */ 3, /* 21 */ 3,
  /* 22 */ 3, /* 23 */ 3,
  /* 24 */ 3, /* 25 */ 3,
  /* 26 */ 3, /* 27 */ 3,
  /* 28 */ 3, /* 29 */ 3, /* 30 */ 3,
  /* 31 */ 3, /* 32 */ 3,
  /* 33 */ 3, /* 34 */ 3,

  // parentheses (outer accent ring)
  /* 35 */ 4, /* 36 */ 4, /* 37 */ 4, /* 38 */ 4, /* 39 */ 4,
  /* 40 */ 4, /* 41 */ 4, /* 42 */ 4, /* 43 */ 4, /* 44 */ 4
};


// ---------------- LED STRIPS ----------------
static Adafruit_NeoPixel rings(RING_LEDS, RINGS_PIN, NEO_GRB + NEO_KHZ800);
static Adafruit_NeoPixel plate(PLATE_LEDS, PLATE_PIN, NEO_GRB + NEO_KHZ800);

// timing
static uint16_t tick = 0;
static uint16_t animTick = 0;

// animation state
static bool ringsDirty = false;
static bool plateDirty = false;
static int8_t platePos = 0;
static int8_t  plateDir = 1;
//static int8_t plateDoubleIndex = 0;   // 0..4

// blinker pulse smoothing
static uint16_t lastLeftPulse  = 0;
static uint16_t lastRightPulse = 0;

// debounce
static bool lastLeftStateStable = LOW;
static bool lastRightStateStable = LOW;
static uint16_t lastLeftChangeTime = 0;
static uint16_t lastRightChangeTime = 0;

// ring direction (single ring only)
static const bool RING_CW = false;

struct PlateTrailProfile {
  int8_t  dir;
  bool    bounce;
  uint8_t r, g, b;
  uint8_t fill_r, fill_g, fill_b;
};

// ---------------- INDEX HELPER ----------------
static inline uint8_t ringIndex(uint8_t i, bool cw) {
  return cw ? i : (RING_LEDS - 1 - i);
}

// ---------------- COMMON HELPERS ----------------
/*
void fillRings(uint8_t r, uint8_t g, uint8_t b) {
  uint32_t colour = rings.Color(r, g, b);
  for (uint8_t i = 0; i < RING_LEDS; i++)
    rings.setPixelColor(i, colour);

  ringsDirty = true;
*/
void fillRings(uint8_t r, uint8_t g, uint8_t b, uint8_t start = 0, uint8_t end = RING_LEDS - 1) {
  if (start >= RING_LEDS) return;
  if (end   >= RING_LEDS) end = RING_LEDS - 1;
  if (start > end) return;

  uint32_t colour = rings.Color(r, g, b);

  for (uint8_t i = start; i <= end; i++) {
    rings.setPixelColor(i, colour);
  }

  ringsDirty = true;
}


void fillPlate(uint8_t r, uint8_t g, uint8_t b) {
  uint32_t colour = plate.Color(r, g, b);
  
  for (uint8_t i = 0; i < PLATE_LEDS; i++) {
    plate.setPixelColor(i, colour);
  }

  plateDirty = true;
}

static inline void fadePlateTo(uint8_t bg_r, uint8_t bg_g, uint8_t bg_b, uint8_t decay) {
  for (uint8_t i = 0; i < PLATE_LEDS; i++) {
    uint32_t c = plate.getPixelColor(i);

    uint8_t r = (uint8_t)(c >> 16);
    uint8_t g = (uint8_t)(c >> 8);
    uint8_t b = (uint8_t)c;

    // move each channel toward background by 'decay' steps
    if (r > bg_r) r = (r - decay > bg_r) ? r - decay : bg_r;
    else if (r < bg_r) r = (r + decay < bg_r) ? r + decay : bg_r;

    if (g > bg_g) g = (g - decay > bg_g) ? g - decay : bg_g;
    else if (g < bg_g) g = (g + decay < bg_g) ? g + decay : bg_g;

    if (b > bg_b) b = (b - decay > bg_b) ? b - decay : bg_b;
    else if (b < bg_b) b = (b + decay < bg_b) ? b + decay : bg_b;

    plate.setPixelColor(i, plate.Color(r, g, b));
  }

  plateDirty = true;
}

static inline void fadePlate(uint8_t decay) { // to black
  fadePlateTo(0, 0, 0, decay);
}

static inline void advancePlatePos(bool bounce) {
  platePos += plateDir;

  if (bounce) {
    if (platePos <= 0) {
      platePos = 0;
      plateDir = +1;
    } else if (platePos >= PLATE_LEDS - 1) {
      platePos = PLATE_LEDS - 1;
      plateDir = -1;
    }
  } else {
    if (platePos < 0)
      platePos = PLATE_LEDS - 1;
    else if (platePos >= PLATE_LEDS)
      platePos = 0;
  }
}

static inline void renderPlateTrailEx(const PlateTrailProfile& profile) {
  if ((animTick % PLATE_STOP_DIV) != 0) return;

  if (!profile.bounce)
    plateDir = (profile.dir == 0) ? +1 : profile.dir;

  fillPlate(profile.fill_r, profile.fill_g, profile.fill_b);

  advancePlatePos(profile.bounce);

  // -------- NORMAL SWEEP (dir != 0) --------
  if (profile.dir != 0) {
    for (uint8_t i = 0; i < PLATE_TRAIL_LEN; i++) {
      int16_t p = platePos - (plateDir * i);
      if (p < 0 || p >= PLATE_LEDS) break;

      uint8_t v = 255 - (i * (255 / PLATE_TRAIL_LEN));
      plate.setPixelColor(
        p,
        plate.Color(
          (uint16_t)profile.r * v / 255,
          (uint16_t)profile.g * v / 255,
          (uint16_t)profile.b * v / 255
        )
      );
    }
  }

  // -------- DOUBLE SWEEP (dir == 0) --------
  else {
    const uint8_t half = PLATE_LEDS / 2;

    // abstract position inside half-domain
    uint8_t pos = platePos % half;

    for (uint8_t i = 0; i < PLATE_TRAIL_LEN; i++) {
      int16_t p = pos - i;
      if (p < 0) break;

      uint8_t v = 255 - (i * (255 / PLATE_TRAIL_LEN));

      uint8_t left  = (half - 1) - p;
      uint8_t right = half + p;

      if (left < PLATE_LEDS)
        plate.setPixelColor(
          left,
          plate.Color(
            (uint16_t)profile.r * v / 255,
            (uint16_t)profile.g * v / 255,
            (uint16_t)profile.b * v / 255
          )
        );

      if (right < PLATE_LEDS)
        plate.setPixelColor(
          right,
          plate.Color(
            (uint16_t)profile.r * v / 255,
            (uint16_t)profile.g * v / 255,
            (uint16_t)profile.b * v / 255
          )
        );
    }
  }

  plateDirty = true;
}

static inline void renderSweepTrailEx(uint8_t start, uint8_t count, const PlateTrailProfile& profile) {
  if ((animTick % RINGS_SWEEP_DIV) != 0) return;

  static int16_t sweepPos = 0;
  static int8_t  sweepDir = +1;

  /* direction is explicitly +1 or -1 */
  sweepDir = (profile.dir >= 0) ? +1 : -1;

  /* fill ring subsection using existing helper */
//  fillRings(
//    profile.fill_r,
//    profile.fill_g,
//    profile.fill_b,
//    start,
//    start + count - 1
//  );

  /* advance position (wrap only) */
  sweepPos += sweepDir;
  if (sweepPos >= count) sweepPos = 0;
  if (sweepPos < 0)      sweepPos = count - 1;

  /* normal sweep with trail */
  for (uint8_t i = 0; i < RINGS_SWEEP_TRAIL_LEN; i++) {
    int16_t p = sweepPos - (sweepDir * i);
    if (p < 0 || p >= count) break;

    uint8_t v = 255 - (i * (255 / RINGS_SWEEP_TRAIL_LEN));

    rings.setPixelColor(
      start + p,
      rings.Color(
        (uint16_t)profile.r * v / 255,
        (uint16_t)profile.g * v / 255,
        (uint16_t)profile.b * v / 255
      )
    );
  }

  ringsDirty = true;
}


//static void renderEyeBlink(int8_t activeLevel, bool turnOn) {
//  uint32_t colour = rings.Color(55, 0, 0);
//
//  for (uint8_t i = 0; i < RING_LEDS; i++) {
//    if (ledY[i] == activeLevel) {
//      rings.setPixelColor(i, turnOn ? colour : 0);
//    }
//  }
//
//  ringsDirty = true;
//}

static inline void updateEmergencyState(bool leftActive, bool rightActive) {
  if (leftActive && rightActive) {
    emergencyLatched = true;
    emergencyLatchTick = tick;
    emergencyReleaseTick = 0;
  } else if (emergencyLatched) {
    // count how long both are inactive
    if (!leftActive && !rightActive) {
      if (emergencyReleaseTick == 0)
        emergencyReleaseTick = tick;
      else if ((uint16_t)(tick - emergencyReleaseTick) >= EMERG_RELEASE_TICKS)
        emergencyLatched = false;
    } else {
      emergencyReleaseTick = 0;
    }
  }
}

// ---------------- RING ANIMATIONS ----------------
void animRingsIdle(uint16_t animTick) {
  uint16_t idle_t = animTick % IDLE_PERIOD_TICKS;

  uint8_t idle_wave =
    (idle_t < IDLE_PERIOD_TICKS / 2)
      ? (uint32_t)idle_t * (IDLE_SPAN * 2) / IDLE_PERIOD_TICKS
      : (uint32_t)(IDLE_PERIOD_TICKS - idle_t) * (IDLE_SPAN * 2) / IDLE_PERIOD_TICKS;

  uint8_t idle_val = IDLE_MIN_BRIGHTNESS + idle_wave;
  uint32_t colour = rings.Color(idle_val, (idle_val / 10) + 1, 0);

  for (uint8_t i = 0; i < RING_LEDS; i++)
    rings.setPixelColor(ringIndex(i, RING_CW), colour);
    //rings.setPixelColor(i, colour);
//  for (uint8_t i = 0; i < 19; i++)
//    rings.setPixelColor(ringIndex(i, RING_CW), colour);
//    //rings.setPixelColor(i, colour);

  fillRings(0, 0, IDLE_MAX_BRIGHTNESS, 35, 44);

  ringsDirty = true;
}

void animRingsStop() {
  /*
  uint32_t colour = rings.Color(STOP_BRIGHTNESS, 10, 0);
  for (uint8_t i = 0; i < RING_LEDS; i++)
    rings.setPixelColor(i, colour);
  */
  
  fillRings(STOP_BRIGHTNESS, 5, 0, 0, 34);
  fillRings(255, 5, 0, 35, 44);
  
  ringsDirty = true;
}

void animRingsTurn(uint16_t animTick) {
  rings.clear();

  uint8_t pos = animTick % RING_LEDS;

  rings.setPixelColor(ringIndex(pos, RING_CW), rings.Color(255, 80, 0));

  ringsDirty = true;
}

void animRingsEmergency(uint16_t animTick) {
  uint8_t phase = (animTick / RINGS_EMERG_DELAY) & 1;
  uint8_t val = phase ? 0 : 55;

  uint32_t colour = rings.Color(val, val / 4, 0);

  for (uint8_t i = 0; i < RING_LEDS; i++)
    rings.setPixelColor(i, colour);

  ringsDirty = true;
}

void animRingsEmergencyRings() {
  if (ringEmergState != RING_EMERG_ACTIVE)
    return;

  // ---- timing gate ----
  if (++ringTick < RINGS_EMERG_DIV)
    return;
  ringTick = 0;

  uint32_t colour = rings.Color(255, 80, 0);
  int8_t level = ringOrder[ringEmergIndex];

  for (uint8_t i = 0; i < RING_LEDS; i++) {
    if (ledRing[i] == level) {
      rings.setPixelColor(i, ringOpening ? colour : 0);
    }
  }

  ringsDirty = true;

  // ---- advance ----
  if (!ringOpening) {
    ringEmergIndex++;
    if (ringEmergIndex >= RING_STEPS) {
      ringEmergIndex = RING_STEPS - 1;
      ringOpening = true;
    }
  } else {
    ringEmergIndex--;
    if (ringEmergIndex < 0) {
      ringEmergIndex = 0;
      ringOpening = false;
    }
  }
}

void startEmergencyRingAnim() {
  ringEmergIndex = 0;
  ringOpening = false;
  ringTick = 0;
  ringEmergState = RING_EMERG_ACTIVE;
}

void stopEmergencyRingAnim() {
  ringEmergState = RING_EMERG_IDLE;
}

void animRingsEyeBlink() {
  if (blinkState != BLINK_ACTIVE)
    return;

  // ---- timing gate ----
  if (++blinkTick < BLINK_STEP_TICKS)
    return;
  blinkTick = 0;

  uint32_t colour = rings.Color(
        (currentMode == MODE_STOP) ? STOP_BRIGHTNESS : IDLE_MAX_BRIGHTNESS, 10, 0);

  int8_t level = blinkOrder[blinkIndex];

  for (uint8_t i = 0; i < RING_LEDS; i++) {
    if (ledY[i] == level) {
      rings.setPixelColor(i, blinkOpening ? colour : 0);
    }
  }

  ringsDirty = true;

  // ---- advance ----
  if (!blinkOpening) {
    if (blinkIndex < BLINK_STEPS - 1) {
      blinkIndex++;
    } else {
      // we have already rendered the last step
      blinkOpening = true;
    }
  } else {
    blinkIndex--;
    if (blinkIndex < 0) {
      blinkState = BLINK_IDLE;
    }
  }
}

void startEyeBlink() {
  /*
  uint32_t colour = rings.Color(STOP_BRIGHTNESS, 0, 0);

  // ensure fully open
  for (uint8_t i = 0; i < RING_LEDS; i++) {
    rings.setPixelColor(i, colour);
  }

  ringsDirty = true;
  */

  blinkIndex = 0;
  blinkOpening = false;
  blinkTick = 0;
  blinkState = BLINK_ACTIVE;
}

// ---------------- NUMBERPLATE ----------------
void animPlateIdle() {
  fillPlate(PLATE_BRIGHTNESS, PLATE_BRIGHTNESS, PLATE_BRIGHTNESS - 5);
}

static const PlateTrailProfile PLATE_IDLE  = { +1, true,  255, 10, 0, PLATE_BRIGHTNESS, PLATE_BRIGHTNESS, PLATE_BRIGHTNESS - 5 };
static const PlateTrailProfile PLATE_STOP  = { +1, true,  255, 80, 0, 0, 0, 0 };
static const PlateTrailProfile PLATE_LEFT  = { -1, false, 255, 80, 0, 0, 0, 0 };
static const PlateTrailProfile PLATE_RIGHT = { +1, false, 255, 80, 0, 0, 0, 0 };
static const PlateTrailProfile PLATE_EMERG = { +1, true,  255, 80, 0, 0, 0, 0 };
static const PlateTrailProfile PLATE_EMERG_DOUBLE = { 0, false, 255, 80, 0, 0, 0, 0 };

void animPlateIdleTrail()  { renderPlateTrailEx(PLATE_IDLE); }
void animPlateStopTrail()  { renderPlateTrailEx(PLATE_STOP); }
void animPlateLeftTrail()  { renderPlateTrailEx(PLATE_LEFT); }
void animPlateRightTrail() { renderPlateTrailEx(PLATE_RIGHT); }
void animPlateEmergTrail() { renderPlateTrailEx(PLATE_EMERG); }
void animPlateEmergDoubleTrail() { renderPlateTrailEx(PLATE_EMERG_DOUBLE); }

void animRingOverlayTrail() { renderSweepTrailEx(19, 16, PLATE_RIGHT); }

/*
void animPlateDoubleSweepTrail() {
  if ((animTick % PLATE_STOP_DIV) != 0)
    return;

  // background
  fillPlate(
    PLATE_EMERG_DOUBLE.fill_r,
    PLATE_EMERG_DOUBLE.fill_g,
    PLATE_EMERG_DOUBLE.fill_b
  );

  // ---- primary heads ----
  int8_t left  = 4 - plateDoubleIndex;
  int8_t right = 5 + plateDoubleIndex;

  uint32_t headColor = plate.Color(
    PLATE_EMERG_DOUBLE.r,
    PLATE_EMERG_DOUBLE.g,
    PLATE_EMERG_DOUBLE.b
  );

  if (left >= 0)
    plate.setPixelColor(left, headColor);

  if (right < PLATE_LEDS)
    plate.setPixelColor(right, headColor);

  // ---- trail ----
  for (uint8_t i = 1; i < PLATE_TRAIL_LEN; i++) {
    uint8_t v = 255 - (i * (255 / PLATE_TRAIL_LEN));

    uint32_t trailColor = plate.Color(
      (uint16_t)PLATE_EMERG_DOUBLE.r * v / 255,
      (uint16_t)PLATE_EMERG_DOUBLE.g * v / 255,
      (uint16_t)PLATE_EMERG_DOUBLE.b * v / 255
    );

    int8_t l = left  + i;
    int8_t r = right - i;

    if (l >= 0 && l < PLATE_LEDS)
      plate.setPixelColor(l, trailColor);

    if (r >= 0 && r < PLATE_LEDS)
      plate.setPixelColor(r, trailColor);
  }

  plateDirty = true;

  // ---- advance ----
  plateDoubleIndex++;
  if (plateDoubleIndex > 4)
    plateDoubleIndex = 0;
}
*/

/*
void animPlateStop() {
  static uint8_t div = 0;
  if (++div < PLATE_STOP_DIV) return;
  div = 0;

  fillPlate(PLATE_BRIGHTNESS, PLATE_BRIGHTNESS, PLATE_BRIGHTNESS);
  plate.setPixelColor(platePos, plate.Color(255, 0, 0));

  //plate.show();
  plateDirty = true;

  platePos += plateDir;
  if (platePos == 0 || platePos == PLATE_LEDS - 1)
    plateDir = -plateDir;
}

void animPlateLeft() {
  fillPlate(PLATE_BRIGHTNESS, PLATE_BRIGHTNESS, PLATE_BRIGHTNESS);
  plate.setPixelColor(platePos, plate.Color(255, 80, 0));

  //plate.show();
  plateDirty = true;

  platePos++;
  if (platePos >= PLATE_LEDS)
    platePos = 0;
}

void animPlateRight() {
  fillPlate(PLATE_BRIGHTNESS, PLATE_BRIGHTNESS, PLATE_BRIGHTNESS);
  plate.setPixelColor(platePos, plate.Color(255, 80, 0));

  //plate.show();
  plateDirty = true;

  if (platePos == 0)
    platePos = PLATE_LEDS - 1;
  else
    platePos--;
}
*/

// ---------------- MODE MGMT ----------------
void setMode(Mode m) {
  if (m != currentMode) {
    currentMode = m;

//    if (m == MODE_EMERGENCY) {
//      startEmergencyRingAnim();
//    } else {
//      stopEmergencyRingAnim();
//    }

    if (m == MODE_STOP) {
      platePos = 0;
      plateDir = 1;
    }
    else if (m == MODE_LEFT) {
      platePos = PLATE_LEDS - 1;
      plateDir = -1;
    }
    else if (m == MODE_RIGHT) {
      platePos = 0;
      plateDir = +1;
    }
  }
}

// ---------------- ANIMATION UPDATE ----------------
void updateAnimation() {
  animTick++;
  tick++;

  delay(LOOP_DELAY);

  // ---------- RINGS ----------
//  if (ringEmergState == RING_EMERG_ACTIVE) {
//    animRingsEmergencyRings();
//  }
//  else 
  if ((blinkState == BLINK_ACTIVE) && (currentMode == MODE_IDLE || currentMode == MODE_STOP)) {
      animRingsEyeBlink();
  } else {
    switch (currentMode) {

      case MODE_IDLE:
        animRingsIdle(animTick);
        animRingOverlayTrail();
        break;

      case MODE_STOP:
        animRingsStop();
        animRingOverlayTrail();
        break;

      case MODE_LEFT:
      case MODE_RIGHT:
        //animRingsTurn(animTick);
        animRingsIdle(animTick);
        break;

      case MODE_EMERGENCY:
        animRingsEmergency(animTick);
        break;
    }
  }

//  // ---- SWEEP OVERLAY (IDLE or STOP) ----
//  if (currentMode == MODE_IDLE || currentMode == MODE_STOP) {
//    animRingOverlayTrail();
//  }

  // ---------- PLATE ----------
//  if (ringEmergState == RING_EMERG_ACTIVE) {
//    animPlateEmergTrail();   // or animPlateIdleOverlay(), etc.
//  }
//  else {
    switch (currentMode) {
  
      case MODE_IDLE:
        animPlateIdleTrail();
        break;
  
      case MODE_STOP:
        animPlateStopTrail();
        break;
  
      case MODE_LEFT:
        animPlateLeftTrail();
        break;
  
      case MODE_RIGHT:
        animPlateRightTrail();
        break;
  
      case MODE_EMERGENCY:
        //animPlateIdleTrail();
        animPlateEmergDoubleTrail();
        break;
    }
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
void loop() {
  static uint8_t loopDivider = 0;
  if (++loopDivider < LOOP_DIVIDER) return;
  loopDivider = 0;

  bool leftState  = digitalRead(PIN_LEFT);
  bool rightState = digitalRead(PIN_RIGHT);
  bool stopActive = digitalRead(PIN_STOP);

  // -------- LEFT DEBOUNCE --------
  if (leftState != lastLeftStateStable)
    lastLeftChangeTime = tick;

  if ((uint16_t)(tick - lastLeftChangeTime) >= BLINKER_DEBOUNCE_TICKS) {
    lastLeftStateStable = leftState;
  }

  // -------- RIGHT DEBOUNCE --------
  if (rightState != lastRightStateStable)
    lastRightChangeTime = tick;

  if ((uint16_t)(tick - lastRightChangeTime) >= BLINKER_DEBOUNCE_TICKS) {
    lastRightStateStable = rightState;
  }

  // -------- RAW PULSE CAPTURE --------
  if (leftState)
    lastLeftPulse = tick;

  if (rightState)
    lastRightPulse = tick;

  bool leftActive =
    ((uint16_t)(tick - lastLeftPulse) < BLINKER_TIMEOUT_TICKS);

  bool rightActive =
    ((uint16_t)(tick - lastRightPulse) < BLINKER_TIMEOUT_TICKS);

  // DEBUG OVERRIDE
  leftActive  = false;
  rightActive = false;
//  stopActive  = true;
  /////////////////

  // -------- EMERGENCY LATCH UPDATE --------
  updateEmergencyState(leftActive, rightActive);

  // -------- MODE PRIORITY --------
  if (stopActive)
    setMode(MODE_STOP);
  //else if (leftActive && rightActive)
  else if (emergencyLatched)
    setMode(MODE_EMERGENCY);
  else if (leftActive)
    setMode(MODE_LEFT);
  else if (rightActive)
    setMode(MODE_RIGHT);
  else
    setMode(MODE_IDLE);

  updateAnimation();
}

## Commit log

2026-01-08 Add KiCad project files
    [left_ring.kicad_sch, plate_light.kicad_sch, right_ring.kicad_sch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]
2026-01-08 Update folder structure
    [left_ring.kicad_sch, plate_light.kicad_sch, right_ring.kicad_sch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]
2026-01-13 Add current production files
    [BOM-zr7-taillight.csv, zr7-taillight.kicad_pcb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]
2026-01-15 Enhance README with PCB and assembly details
    Added details and images for PCB, assembly, and diffuser sections.
2026-01-15 Enhance README with PCB and assembly details
    Added details about PCB, assembly, and diffuser sections with images.
2026-01-19 Add Relay section to README with images
    Added Relay section with images and details.

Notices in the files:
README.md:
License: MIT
